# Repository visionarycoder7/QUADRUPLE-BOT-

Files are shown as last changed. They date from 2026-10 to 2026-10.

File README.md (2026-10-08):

# 🐾 8-DOF Quadruped Robot

An **8-DOF quadruped robot** developed as part of the **WTL & MeitY Certification-Based Industrial Training Programme** by **Group-E, Department of Electronics & Communication Engineering, Cooch Behar Government Engineering College (CGEC)**.

The project combines **embedded systems, servo control, mechanical CAD design, 3D printing, and robotics** to develop a four-legged robotic platform capable of stable standing and serving as a foundation for walking gait and autonomous navigation.

---

## 📌 Project Overview

A quadruped robot is a four-legged mobile robot designed to achieve locomotion using coordinated leg movements.

In this project, each leg contains:

- **1 Hip joint**
- **1 Knee joint**

This provides:

> **4 legs × 2 DOF = 8 Degrees of Freedom**

The robot uses an **ESP32** as the central controller and a **PCA9685 16-channel PWM servo driver** to control eight SG90S metal-gear micro servos.

The mechanical structure was designed using **FreeCAD** and fabricated using **FDM 3D printing**.

---

## 🎯 Objectives

The major objectives of the project are:

- Design and develop a functional **8-DOF quadruped robot**
- Implement servo control using an **ESP32**
- Control multiple servos using a **PCA9685 PWM driver**
- Design the robot chassis using **FreeCAD**
- Fabricate mechanical components using **FDM 3D printing**
- Develop and test the electronics and servo-control system
- Implement a stable standing pose
- Establish a foundation for future walking and turning gaits
- Gain practical experience in:
  - Embedded Systems
  - Robotics
  - Electronics
  - Mechanical Design
  - CAD Modelling
  - Additive Manufacturing

---

## 🧠 System Architecture

```text
                 ┌─────────────────────┐
                 │       ESP32          │
                 │  Central Controller  │
                 └──────────┬──────────┘
                            │
                     I2C Communication
                     SDA → GPIO 21
                     SCL → GPIO 22
                            │
                            ▼
                 ┌─────────────────────┐
                 │      PCA9685        │
                 │  16-Channel PWM     │
                 │    Servo Driver     │
                 └──────────┬──────────┘
                            │
              ┌─────────────┼─────────────┐
              │             │             │
              ▼             ▼             ▼
          Hip Servos    Knee Servos    Other Channels
              │             │
              └─────────────┼─────────────┘
                            ▼
                   8 × SG90S Servos
                            │
                            ▼
                    Quadruped Robot
```

### Power Architecture

The ESP32 communicates with the PCA9685 through I2C, while the servo power rail is supplied separately.

```text
External 5V Supply
       │
       ▼
PCA9685 V+ ───────► Servo Power Rail
       │
       ├── CH0 → Front Left Hip
       ├── CH1 → Front Left Knee
       ├── CH2 → Front Right Hip
       ├── CH3 → Front Right Knee
       ├── CH4 → Rear Left Hip
       ├── CH5 → Rear Left Knee
       ├── CH6 → Rear Right Hip
       └── CH7 → Rear Right Knee
```

> ⚠️ **Important:** The PCA9685 `V+` terminal requires an external 5V supply for powering the servos. The PCA9685 `VCC` connection to the ESP32 is for logic power and is not the servo power rail.

---

## 🔌 Electronics Components

| Component | Quantity | Purpose |
|---|---:|---|
| ESP32 Development Board | 1 | Main controller |
| PCA9685 16-Channel PWM Driver | 1 | Multi-servo control |
| SG90S Metal Gear Servo | 8 | Hip & knee actuation |
| 5V External Supply | 1 | Servo power |
| 3D Printed Chassis | 1 set | Mechanical structure |
| Power Switch | 1 | Power control |

---

## 📡 ESP32 → PCA9685 Connections

| ESP32 | PCA9685 |
|---|---|
| 3.3V | VCC |
| GND | GND |
| GPIO 21 | SDA |
| GPIO 22 | SCL |

### PCA9685 I2C Address

The PCA9685 was verified using an I2C scanner.

```text
I2C Device Found:
0x40
```

Therefore:

```text
PCA9685 I2C Address = 0x40
```

---

## 🦿 Servo Channel Mapping

The eight servos are connected to PCA9685 channels **CH0–CH7**.

| Channel | Location | Joint |
|---|---|---|
| CH0 | Front Left | Hip |
| CH1 | Front Left | Knee |
| CH2 | Front Right | Hip |
| CH3 | Front Right | Knee |
| CH4 | Rear Left | Hip |
| CH5 | Rear Left | Knee |
| CH6 | Rear Right | Hip |
| CH7 | Rear Right | Knee |

---

# 🛠️ Mechanical Design

The complete chassis was designed using **FreeCAD** using a parametric modelling workflow.

The robot consists primarily of:

1. Core Body
2. Head Box
3. Four Upper Legs
4. Four Lower Legs

### Mechanical Structure

```text
                   HEAD BOX
              ┌───────────────┐
              │ ESP32 +       │
              │ PCA9685       │
              └───────┬───────┘
                      │
              ┌───────┴───────┐
              │   CORE BODY   │
              └─┬───────────┬─┘
                │           │
          Upper Leg     Upper Leg
                │           │
          Lower Leg     Lower Leg
                │           │
              Foot        Foot

          Rear legs follow the
          same 2-DOF structure.
```

---

## 📐 Component Dimensions

| Component | Dimensions |
|---|---|
| Core Body | 110 × 85 × 4 mm |
| Head Box | 85 × 65 × 45 mm |
| Upper Leg | 45 × 10 × 5 mm |
| Lower Leg | 55 × 10 × 5 mm |

### Core Body

The central chassis contains mounting positions for the four hip servos.

### Head Box

The head box houses:

- ESP32
- PCA9685
- Power switch
- Provision for future sensors

### Upper Leg

Each upper leg is driven by a hip servo.

### Lower Leg

Each lower leg is driven by a knee servo.

---

# 🖨️ 3D Printing

The mechanical components were fabricated using **Fused Deposition Modelling (FDM)**.

### Manufacturing Workflow

```text
FreeCAD CAD Model
       ↓
     STL Export
       ↓
      Slicer
       ↓
    G-code
       ↓
   FDM Printer
       ↓
3D Printed Component
       ↓
    Assembly
```

The components were fabricated in the **CGEC 3D Printing Lab**.

---

## 🧱 Materials

Two thermoplastic materials were used:

### ABS

Used for:

- Core Body
- Head Box

Selected for its stiffness and suitability for structural components.

### PLA

Used for:

- 4 × Upper Legs
- 4 × Lower Legs

---

## ⚙️ Printing Parameters

| Parameter | Value |
|---|---:|
| Layer Height | 0.2 mm |
| Infill Density | 40% |
| Perimeter Walls | 4 |
| Nozzle Diameter | 0.4 mm |
| Print Speed | 50 mm/s |
| Support | As required |

---

# 💻 Software & Programming

The project uses the **Arduino IDE** with ESP32 board support.

### Libraries

```cpp
#include <ESP32Servo.h>
#include <Wire.h>
#include <Adafruit_PWMServoDriver.h>
```

### Libraries Used

| Library | Purpose |
|---|---|
| ESP32Servo | Direct servo control using ESP32 PWM |
| Wire | I2C communication |
| Adafruit_PWMServoDriver | PCA9685 servo control |

---

# 🧪 Testing & Debugging

One of the major practical debugging challenges was related to the **PCA9685 servo power rail**.

### Problem

Initially, all eight servos were unresponsive.

The first assumption could have been a problem with:

- ESP32
- I2C communication
- PCA9685
- Software
- Servo connections

However, an I2C scan confirmed:

```text
PCA9685 detected at:
0x40
```

This confirmed that the ESP32 and PCA9685 were communicating correctly.

### Root Cause

The PCA9685 `V+` servo power rail was measured at:

```text
0.10 V
```

instead of the expected approximately:

```text
4.8 – 5.2 V
```

### Solution

An external 5V supply was connected directly to the PCA9685 `V+` terminal.

After the correction:

```text
V+ = 4.92 – 5.05 V
```

The servos immediately responded.

### Key Lesson

> **Always verify the actuator power rail before assuming that the problem is caused by firmware or communication.**

---

# ✅ Testing Results

The complete servo system was tested after resolving the power issue.

### I2C Test

```text
ESP32
  ↓
GPIO21 / GPIO22
  ↓
SDA / SCL
  ↓
PCA9685
  ↓
0x40
```

### Servo Test

All eight servos successfully passed the individual movement test.

| Servo | Channel | 0° | 180° |
|---|---|:---:|:---:|
| Front Left Hip | CH0 | ✅ | ✅ |
| Front Left Knee | CH1 | ✅ | ✅ |
| Front Right Hip | CH2 | ✅ | ✅ |
| Front Right Knee | CH3 | ✅ | ✅ |
| Rear Left Hip | CH4 | ✅ | ✅ |
| Rear Left Knee | CH5 | ✅ | ✅ |
| Rear Right Hip | CH6 | ✅ | ✅ |
| Rear Right Knee | CH7 | ✅ | ✅ |

### Result

**All 8 servos successfully operated across the tested 0°–180° range.**

---

# 🚧 Development Status

The project was divided into nine development phases.

| Phase | Development Stage | Status |
|---:|---|---|
| 1 | Component Verification | ✅ Complete |
| 2 | CAD Design in FreeCAD | ✅ Complete |
| 3 | 3D Printing | ✅ Complete |
| 4 | Servo Calibration | ✅ Complete |
| 5 | Standing Pose | ✅ Complete |
| 6 | Walking Gait | 🔄 In Progress |
| 7 | Turning Gait | 📋 Planned |
| 8 | Sensor Integration | 📋 Planned |
| 9 | Autonomous Navigation | 🔮 Future |

### Current Progress

```text
Completed:  ██████████░░░░░░░░  5 / 9 phases
```

The presentation reports approximately **55% phase completion**.

---

# 🧭 Future Development

The project is intended to evolve beyond the current standing-pose platform.

### Phase 6 — Walking Gait

Develop coordinated leg trajectories and walking patterns using the eight available degrees of freedom.

Potential future implementation:

```text
Inverse Kinematics
       ↓
Leg Trajectory Generation
       ↓
Joint Angle Calculation
       ↓
Servo Commands
       ↓
Walking Gait
```

### Phase 7 — Turning

Implement coordinated movements that allow the robot to turn left and right.

### Phase 8 — Sensor Integration

Future sensors can be integrated to provide environmental awareness.

Possible applications include:

- Obstacle detection
- Distance measurement
- Orientation sensing
- Environmental monitoring

### Phase 9 — Autonomous Navigation

The ESP32's wireless capability provides a foundation for future:

- Wireless teleoperation
- Remote control
- Autonomous navigation
- OTA firmware updates

---

# 🌐 Potential Applications

Quadruped robots can be adapted for several real-world applications:

- 🔍 Search and rescue
- ⚙️ Rough-terrain inspection
- 🎖️ Defence and reconnaissance
- 🏥 Medical and rehabilitation assistance
- 🔬 Robotics research
- 🏭 Industrial inspection
- 🏗️ Infrastructure monitoring

---

# 📁 Suggested Repository Structure

```text
Quadruped-Robot/
│
├── README.md
│
├── Arduino/
│   ├── Servo_Test/
│   │   └── Servo_Test.ino
│   │
│   ├── I2C_Scanner/
│   │   └── I2C_Scanner.ino
│   │
│   └── PCA9685_Control/
│       └── PCA9685_Control.ino
│
├── CAD/
│   ├── Core_Body/
│   ├── Head_Box/
│   ├── Upper_Leg/
│   ├── Lower_Leg/
│   └── Assembly/
│
├── 3D_Models/
│   ├── STL/
│   └── GCODE/
│
├── Documentation/
│   └── Quadruped_Robot_Presentation.pptx
│
└── Images/
    ├── CAD/
    ├── 3D_Printing/
    ├── Electronics/
    └── Final_Robot/
```

---

**WTL & MeitY Certification-Based Industrial Training Programme**

**Department of Electronics & Communication Engineering**  
**Cooch Behar Government Engineering College**  
**2026**

---

# 📚 References

1. Previous Batch Project Report — *3D Printing and Embedded Systems*, CGEC, WTL & MeitY Project, 2024.
2. Espressif Systems — *ESP32 Technical Reference Manual*, v5.3.
3. NXP Semiconductors — *PCA9685 16-channel 12-bit PWM I2C-bus LED Controller Datasheet*.
4. Tower Pro — *SG90S Metal Gear Micro Servo Datasheet*.
5. FreeCAD Community — *FreeCAD: Your Own 3D Parametric Modeler*.

---

# ⭐ Key Takeaways

This project provided hands-on experience in the complete development cycle of a robotic system:

```text
Concept
   ↓
Electronics Design
   ↓
Component Testing
   ↓
CAD Modelling
   ↓
3D Printing
   ↓
Mechanical Assembly
   ↓
Embedded Programming
   ↓
Servo Calibration
   ↓
Standing Pose
   ↓
Walking Gait
   ↓
Autonomous Navigation
```

The completed platform establishes a **functional 8-DOF quadruped hardware and software foundation**, with future work focused on walking gait generation, turning, sensor integration, and autonomous navigation.

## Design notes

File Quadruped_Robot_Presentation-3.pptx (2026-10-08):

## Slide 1

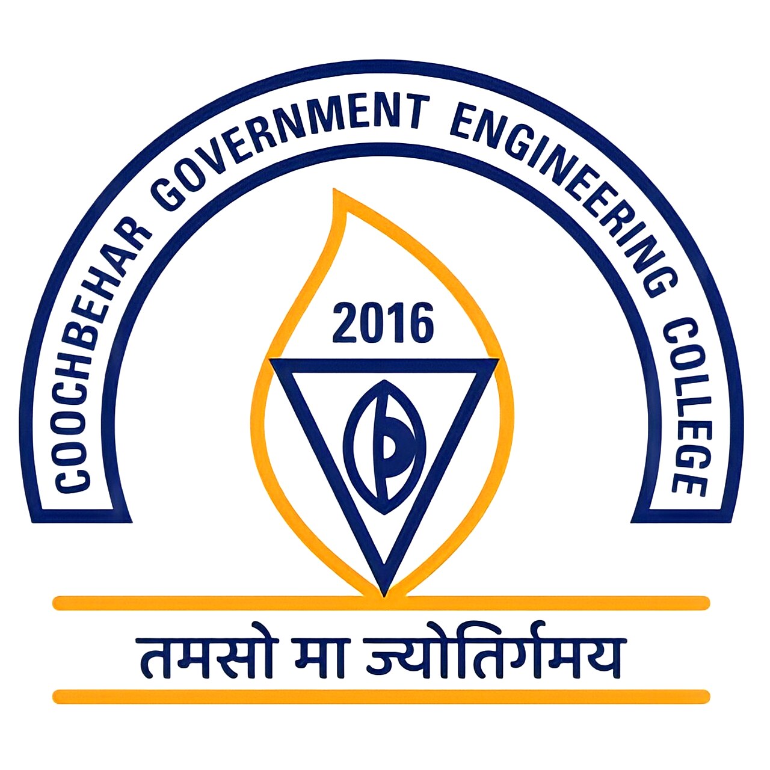
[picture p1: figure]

QUADRUPED ROBOT DEVELOPMENT

━━━━━━━━━━━━━━━━━━━━━━━━━━━━━━━━━━━━━━━━━━━━━

Certification-Based Industrial Training

WTL & MeitY Project | Group-E

Department of Electronics & Communication Engineering

Cooch Behar Government Engineering College | 2026

Guided by: Dr. Palash Das (ECE) | Mrs. Susmita Banik Barik (Project Eng., WTL) | Mr. Arijit Bhunia | Mr. Bhaskar Mondal

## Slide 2

Team Members — Group E

Department of ECE, CGEC | WTL & MeitY Project | 2026

Quadruped Robot Development | Group-E | ECE Dept., CGEC | WTL & MeitY | 2026

Name

Roll No.

Reg. ID

GUIDED BY

Dr. Palash Das

ECE

Mrs. Susmita

Banik Barik

Proj. Eng., WTL

Mr. Arijit Bhunia

Proj. Co-ord.

Mr. Bhaskar

Mondal

Faculty, WTL

2/21

1

2

Sarupya Guha

Sohan Ghosh

34900323046

34900323050

FS08A0198

FS08A0202

3

Sayan Sarkar

34900323048

FS08A0157

4

Debanjan Chakraborty

34900323015

FS08A0154

5

6

Joydip Das

Aushi Sarkar

34900323020

34900323011

FS08A0220

FS08A0288

7

Anupam Dutta

34900323003

FS08A0206

8

9

Bikkram Das

Biraj Sarkar

34900323012

34900323013

FS08A0528

FS08A0239

10

Soumyajit Pandit

34900323052

FS08A0189

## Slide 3

Project Objective

What are we building and why?

Design, fabricate & program a fully functional 8-DOF Quadruped Robot

Use affordable, open-source components and tools (ESP32 + FreeCAD + FDM printing)

Core hardware: ESP32 microcontroller | PCA9685 16-ch servo driver | 8 × SG90S servos

Chassis designed in FreeCAD — fabricated with FDM 3D printing (PLA+ & ABS)

Hands-on experience across: Electronics • Mechanical Design • Additive Manufacturing

End goal: Robot capable of standing stably and executing a walking gait

Future roadmap: Sensor integration → Autonomous navigation

Aligned with GoI skills development initiative under WTL & MeitY programme

Quadruped Robot Development | Group-E | ECE Dept., CGEC | WTL & MeitY | 2026

▶

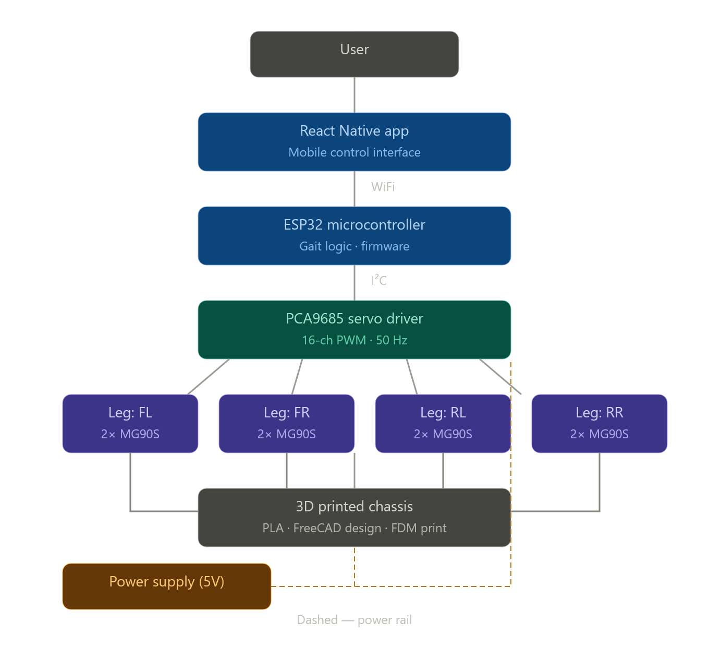
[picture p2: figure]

▶

▶

▶

▶

▶

▶

▶

3/21

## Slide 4

Introduction — What is a Quadruped Robot?

A legged mobile robot that moves on four limbs — mimicking dogs, horses, insects

Unlike wheeled robots, quadrupeds navigate uneven terrain, climb stairs, step over obstacles

Each leg has 2+ joints providing degrees of freedom for stable gait generation

This robot: Hip joint + Knee joint per leg → 8 DOF for locomotion

Notable examples: Boston Dynamics Spot • Unitree Go1 • University research platforms

Quadruped Robot Development | Group-E | ECE Dept., CGEC | WTL & MeitY | 2026

▶

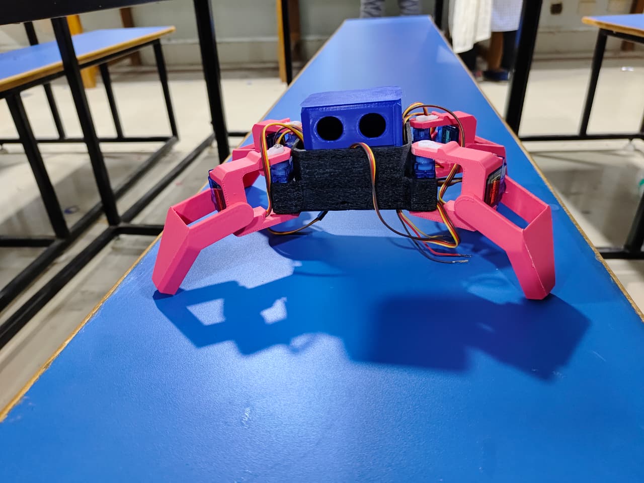
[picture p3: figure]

▶

▶

▶

▶

8 DOF

Locomotion
(4 hips + 4 knees)

Static Head

Head
is stationary

8 Total

SG90S
Servos

3 Domains

Electronics
Mechanical
3D Printing

4/21

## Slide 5

Real-World Applications of Quadruped Robots

Quadruped Robot Development | Group-E | ECE Dept., CGEC | WTL & MeitY | 2026

🔍 Search & Rescue

Navigates rubble, collapsed structures and disaster zones where wheels cannot go

🏥 Medical / Rehab

Companion and assistive robots for elderly care and rehabilitation

⚙ Rough Terrain

Pipeline inspection, mining surveys, and remote area monitoring

🔬 Research Platform

Studying locomotion algorithms, control theory, and AI-based navigation

🎖 Military / Defence

Cargo carrying, reconnaissance missions, and hazardous environment scouting

🏭 Industrial

Automated factory floor inspection and infrastructure monitoring

5/21

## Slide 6

Why ESP32? & Why 3D Printing?

Quadruped Robot Development | Group-E | ECE Dept., CGEC | WTL & MeitY | 2026

ESP32 — Central Controller

3D Printing — Chassis Fabrication

▶

Dual-core 240 MHz processor — powerful yet low-cost

▶

Rapid iteration on part dimensions without tooling cost

▶

▶

Built-in Wi-Fi & Bluetooth for wireless control

Supports I2C and SPI for peripheral communication

▶

▶

Customised mounting positions for every component

Fabricate geometrically complex parts cheaply

PLA+ → structural rigidity for Core Body & Head Box

ABS → flexibility & impact resistance for leg links

▶

Well-supported Arduino IDE ecosystem

▶

▶

ESP32Servo library — direct servo control via PWM

▶

▶

Wireless capability → OTA updates, remote teleoperation

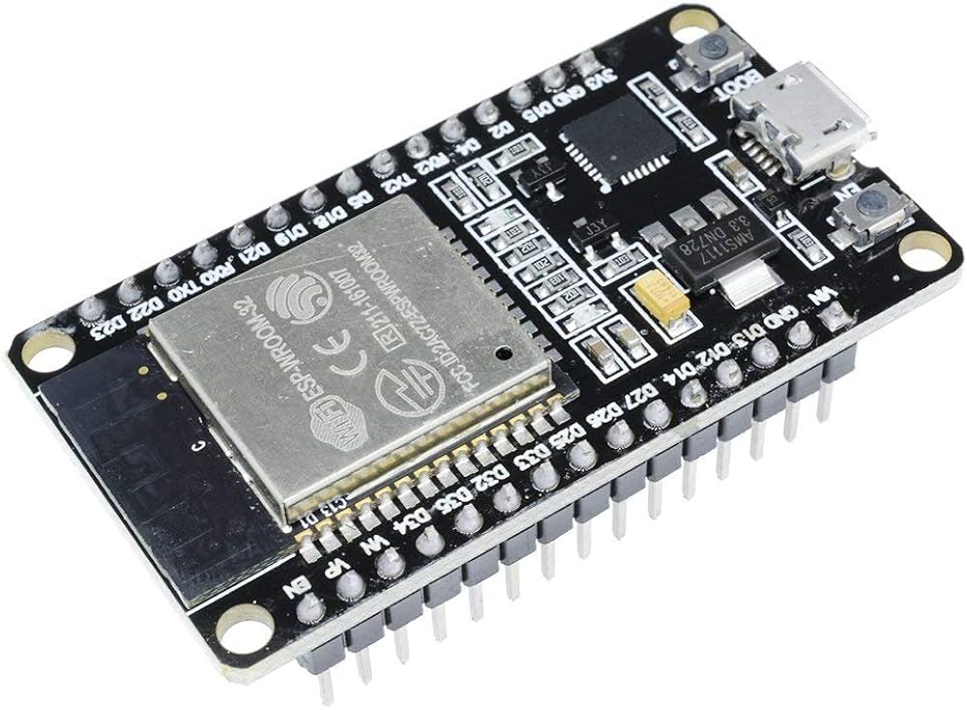
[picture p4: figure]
SquadPixel Esp-32 Wifi, Bluetooth, Dual Core Chip Development Board (ESP-WROOM-32) : Amazon.in: Fashion

▶

Entire robot chassis printed in the CGEC 3D Printing Lab

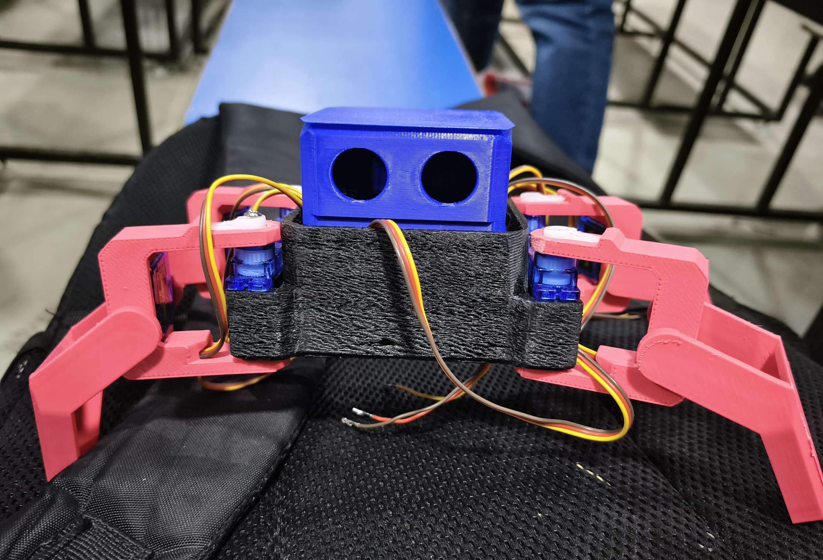
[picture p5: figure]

6/21

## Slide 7

Development Roadmap — 9-Phase Journey

From component verification to autonomous navigation

📌 This report covers Phases 1–5 in detail. Phases 6–9 form the future roadmap.

Quadruped Robot Development | Group-E | ECE Dept., CGEC | WTL & MeitY | 2026

Phase 1

Servo &
MCU Test

Complete

Phase 2

CAD
Design

Complete

Complete

Phase 3

3D
Printing

Complete

Phase 4

Assembly

Complete

In Progress / Planned

Phase 5

Standing
Pose

Complete

Phase 6

Walking
Gait

In Progress

Future Roadmap

Phase 7

Turning
Gait

Planned

Phase 8

Sensor
Integration

Future

Phase 9

Autonomous
Nav.

Future

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
7/21

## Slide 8

Electronics Architecture

4-Layer electronics stack

Layer 1 — Central Controller

ESP32 Dev Board (I2C Master, Dual-core 240 MHz)

Layer 2 — Servo Driver

PCA9685 16-Channel PWM Driver (I2C Slave @ 0x40)

Layer 3 — Actuators

8× SG90S Metal Gear Micro Servos (4 Hip + 4 Knee)

Layer 4 — Power Supply

External 5V Supply → PCA9685 V+ Servo Rail

Quadruped Robot Development | Group-E | ECE Dept., CGEC | WTL & MeitY | 2026

ESP32 → PCA9685 Wiring

ESP32 Pin

3.3V

PCA9685 Pin

VCC

▼

GND

GND

▼

GPIO21

GPIO22

SDA

SCL

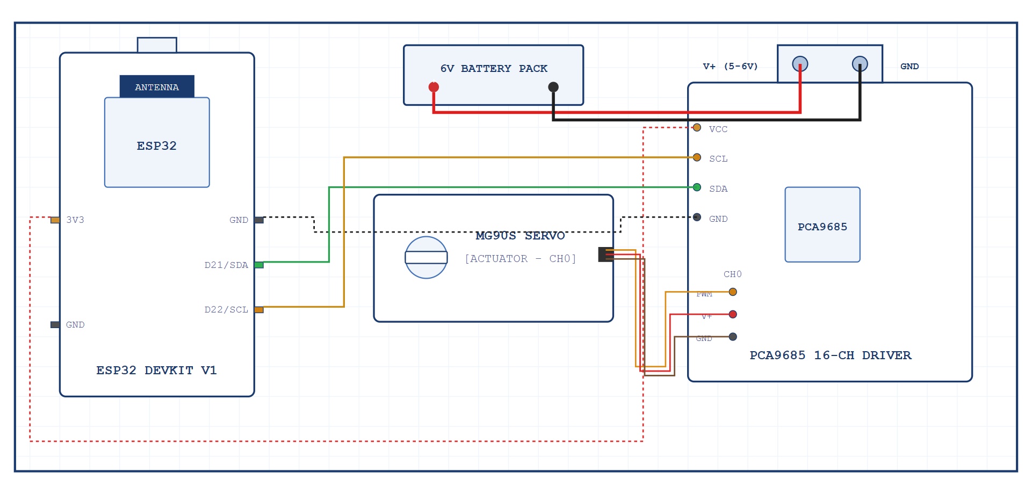
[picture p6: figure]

⚠ PCA9685 V+ rail MUST have
an external 5V supply (separate from VCC)

▼

8/21

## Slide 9

Servo Channel Mapping

PCA9685 CH0–CH7 → 8 SG90S servos

Quadruped Robot Development | Group-E | ECE Dept., CGEC | WTL & MeitY | 2026

CH0

Front Left Hip

Type: Hip

CH5

Rear Left Knee

Type: Knee

CH1

Front Left Knee

Type: Knee

CH6

Rear Right Hip

Type: Hip

CH2

Front Right Hip

Type: Hip

CH7

Rear Right Knee

Type: Knee

CH3

Front Right Knee

Type: Knee

CH4

Rear Left Hip

Type: Hip

Hip Servo

Knee Servo

Head Servo

9/21

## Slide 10

Critical Discovery — Servo Power Rail Issue

Real-world debugging experience during Phase 1

All 8 servos were completely unresponsive when controlled via PCA9685

I2C scanner confirmed PCA9685 at address 0x40 — ESP32, I2C bus, and chip all functioning correctly

V+ rail measured only 0.10 V (expected 4.8–5.2 V) — servo power rail NOT connected to external 5V supply

Connected 5V directly to PCA9685 V+ terminal → Servos responded immediately. V+ measured 4.92–5.05 V

Always verify servo rail voltage FIRST before suspecting firmware or I2C communication issues

Quadruped Robot Development | Group-E | ECE Dept., CGEC | WTL & MeitY | 2026

⚠ SYMPTOM

🔍 I2C DIAGNOSIS

🔎 ROOT CAUSE

✅ RESOLUTION

📖 LESSON

10/21

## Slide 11

Mechanical Architecture & Component Dimensions

FreeCAD-designed chassis — all parts 3D printed

Quadruped Robot Development | Group-E | ECE Dept., CGEC | WTL & MeitY | 2026

Structural Overview

Component Dimensions

▶

Two main assemblies: Head Box (electronics enclosure) + Core Body (central chassis)

Head Box — houses ESP32, PCA9685, power switch + future sensor mount provision

Core Body — mounts all 4 hip servos (4 total on chassis)

Component

Core Body

Dimensions (mm)

110 × 85 × 4

Notes

4 hip mounts

▶

▶

Head Box

85 × 65 × 45

Wall 2.5 mm — ESP32, PCA9685

▶

Each leg: Upper Leg (hip-driven) + Lower Leg (knee-driven) → 2 links per leg

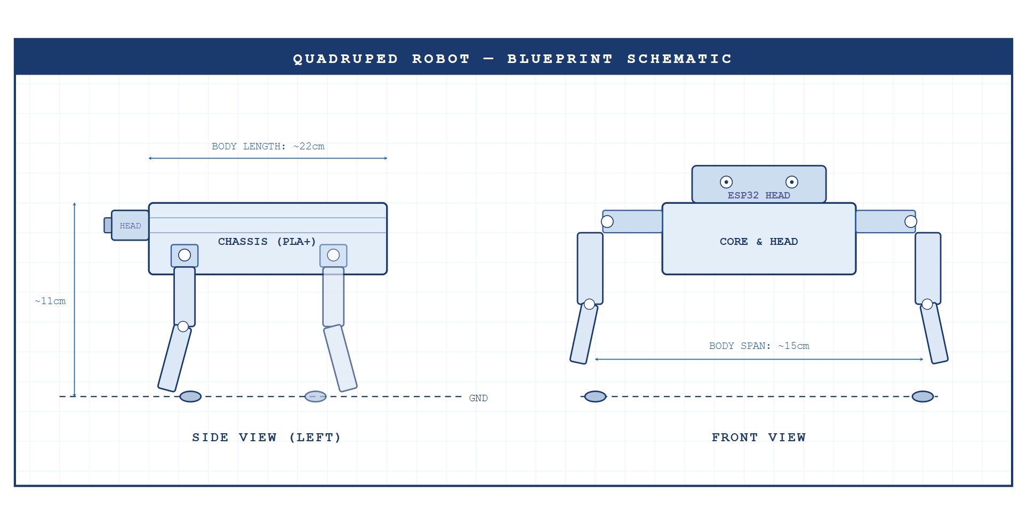
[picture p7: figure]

Upper Leg ×4

45 × 10 × 5

PLA+ — hip servo driven

Lower Leg ×4

55 × 10 × 5

PLA+ — knee servo driven

11/21

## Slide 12

FreeCAD Design Workflow

Part Design workbench — parametric modelling

Quadruped Robot Development | Group-E | ECE Dept., CGEC | WTL & MeitY | 2026

1

Core Body

Base 110×85×4 mm plate with 4 symmetric hip servo pockets and central head servo mount

4

Upper Leg

45 mm PLA link with servo horn connection hole at proximal end

2

Head Box

Enclosure designed around ESP32 and PCA9685 PCB footprints (85×65×45 mm)

5

Hip

Lower Leg

Four symmetric press-fit pockets at FL, FR, RL, RR corners

55 mm PLA link with foot pad boss at distal (terminal) end

3

4

Hip Servo Mounts

Four symmetric press-fit pockets at FL, FR, RL, RR corners

6

Assembly

All bodies assembled in FreeCAD Assembly with correct spacing and constraints

12/21

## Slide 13

3D Printing Process — FDM Technology

CAD → STL → G-code → Print

Fused Deposition Modelling (FDM): thermoplastic filament melted & deposited layer-by-layer | Workflow: CAD Model → STL Export → Slicer (G-code) → 3D Printer

Quadruped Robot Development | Group-E | ECE Dept., CGEC | WTL & MeitY | 2026

Material Selection

Slicer Settings

ABS

Core Body, Head Box

High stiffness, low warping, easy to print

Parameter

Value

Layer Height

Infill Density

0.2 mm

40%

PLA

Upper Leg, Lower Leg (×4 each)

Toughness & flexibility for repeated bending/impact loads

Perimeter Walls

4

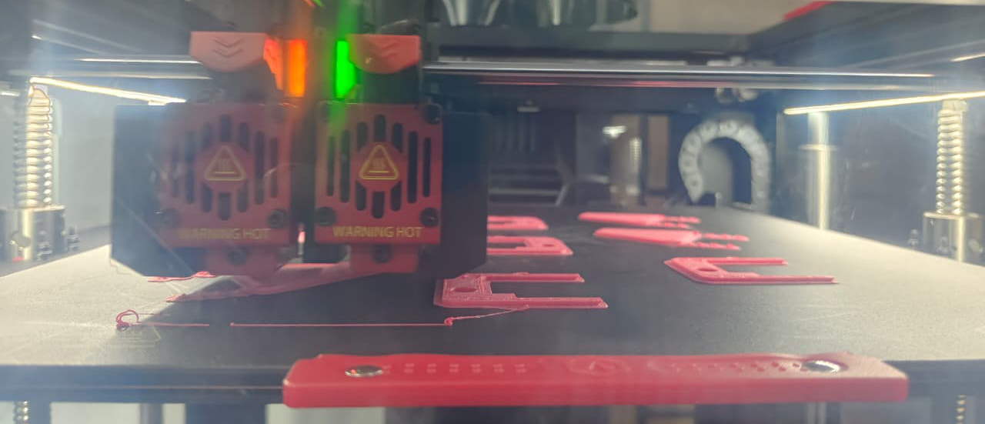
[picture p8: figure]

Nozzle Diameter

Print Speed

0.4 mm

50 mm/s

Support

As required

13/21

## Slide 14

3D Printing in the Lab

Fabrication of quadruped robot components at CGEC 3D Printing Lab

Quadruped Robot Development | Group-E | ECE Dept., CGEC | WTL & MeitY | 2026

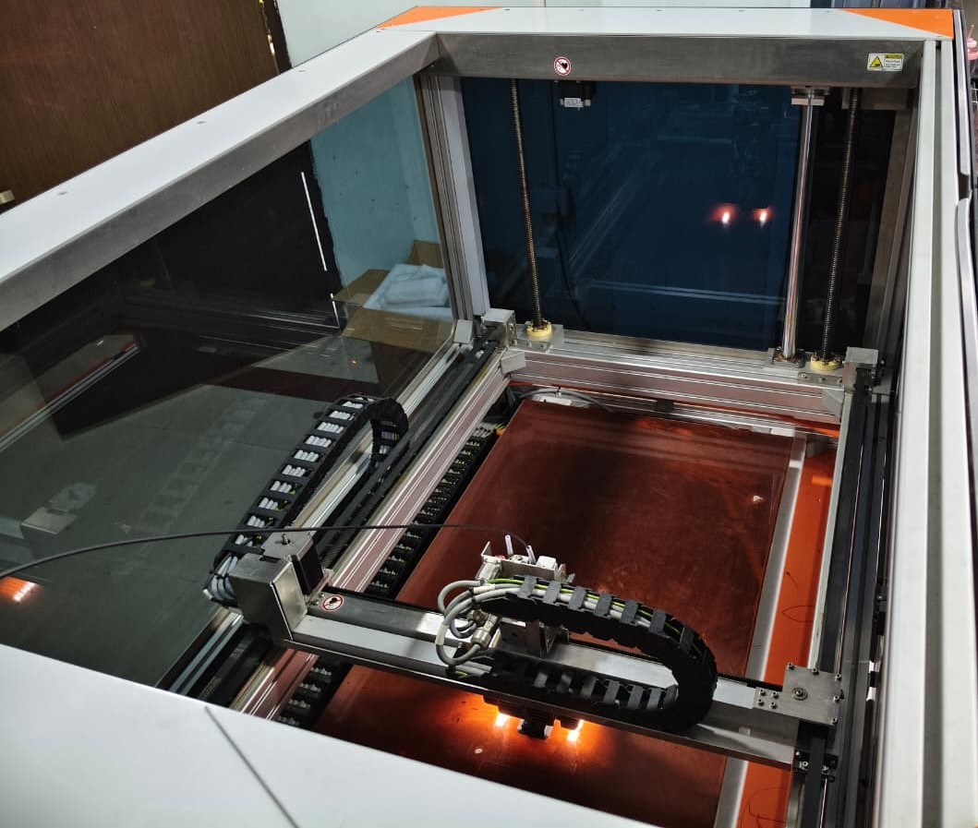
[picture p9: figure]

3D Printer (FDM) in the CGEC Lab during fabrication of the Core Body and Head Box using ABS.

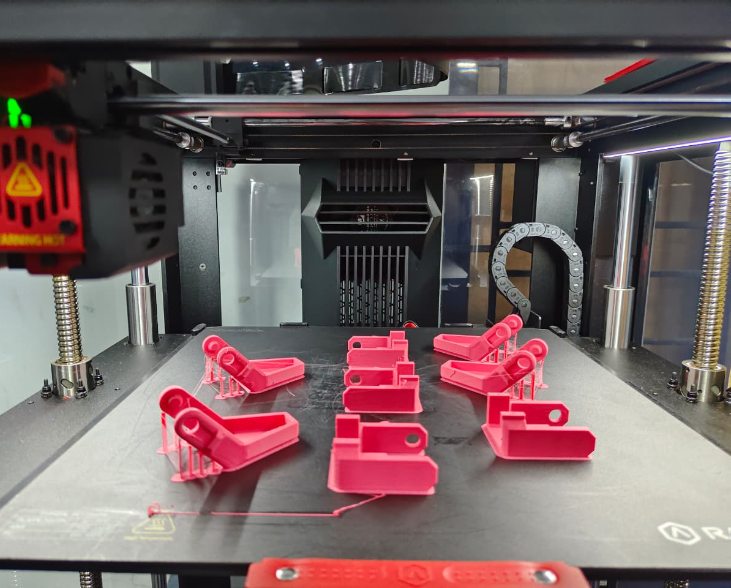
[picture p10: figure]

Fabricated leg components (Upper and Lower leg segments) printed in magenta PLA for high layer adhesion and impact strength.

14/21

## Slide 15

Products Made — 3D Printed Parts

19 total printed components

Description

Quadruped Robot Development | Group-E | ECE Dept., CGEC | WTL & MeitY | 2026

Part

Material

Dimensions

Qty

Core Body

ABS

110×85×4 mm

1

Central chassis; 4 hip mounts; 4mm thickness for bending rigidity

Head Box

ABS

85×65×45 mm

1

Electronics enclosure for ESP32, PCA9685 & power switch; 2.5mm walls; future sensor provision

Upper Leg

PLA

45×10×5 mm

4

Hip-servo driven link; servo horn attachment hole at proximal end

Lower Leg

PLA

55×10×5 mm

4

Knee-servo driven link; foot pad boss at distal terminal end

15/21

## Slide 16

Arduino Programming

Arduino IDE + ESP32 board support package

Quadruped Robot Development | Group-E | ECE Dept., CGEC | WTL & MeitY | 2026

Development Environment & Libraries

// Servo Test Code — ESP32 direct GPIO18

#include <ESP32Servo.h>

Servo myServo;

void setup() {

myServo.attach(18); // GPIO18

}

void loop() {

myServo.write(0); delay(1000);

myServo.write(90); delay(1000);

myServo.write(180); delay(1000);

}

ESP32Servo

Direct servo control via GPIO PWM

Wire

I2C communication for PCA9685

Adafruit_PWMServoDriver

High-level PCA9685 servo control

Code Listings

Listing 1

Servo Test Code: Direct GPIO18 sweep — 0° → 90° → 180° per servo

Listing 2

PCA9685 I2C Scanner: Scans I2C bus, confirms address 0x40

Listing 3

I2C Scan Output: Expected serial monitor: 'I2C device found at 0x40'

Listing 4

PCA9685 Servo Control: All-channel sweep through Adafruit PWM library

16/21

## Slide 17

Results & Testing

I2C verification · Power rail · All-servo sweep

Quadruped Robot Development | Group-E | ECE Dept., CGEC | WTL & MeitY | 2026

I2C Communication Verification

Individual Servo Test Results (All 8 Passed)

PCA9685 confirmed at address 0x40 via I2C scanner

Full chain validated: ESP32 → GPIO21/22 → SDA/SCL → PCA9685

1

Function

Front Left Hip (CH0)

0°

✓ Pass

180°

✓ Pass

Power Rail Diagnosis & Resolution

2

Front Left Knee (CH1)

✓ Pass

✓ Pass

Before fix: V+ = 0.10 V (expected 4.8–5.2 V)

3

Front Right Hip (CH2)

✓ Pass

✓ Pass

After fix: V+ = 4.92–5.05 V → All servos responded immediately

4

5

Front Right Knee (CH3)

Rear Left Hip (CH4)

✓ Pass

✓ Pass

✓ Pass

✓ Pass

6

Rear Left Knee (CH5)

✓ Pass

✓ Pass

7

Rear Right Hip (CH6)

✓ Pass

✓ Pass

8

Rear Right Knee (CH7)

✓ Pass

✓ Pass

17/21

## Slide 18

Development Phase Status

Current progress across all 9 phases

Quadruped Robot Development | Group-E | ECE Dept., CGEC | WTL & MeitY | 2026

1

Component Verification

Complete

6

Walking Gait

In Progress

2

CAD Design in FreeCAD

Complete

7

Turning Gait

Planned

3

3D Printing All Parts

Complete

8

Sensor Integration

Planned

4

Servo Calibration

Complete

9

Autonomous Navigation

Future

5

Standing Pose

Complete

55% Complete (5 of 9 Phases)

18/21

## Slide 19

Conclusion

Key achievements and future roadmap

Systematic debugging validated: I2C chain, servo power rail fix, all 8 servos operational across full 0°–180° range

Parametric FreeCAD CAD workflow mastered: , press-fit tolerances, STL export → design-for-manufacture skills

Hands-on material selection (PLA & ABS), slicer optimization, and print quality assessment in CGEC Lab

Fully functional 8-DOF quadruped hardware + software stack built — validated foundation for walking gait development

Roadmap: Phase 6 Walking Gait (IK) → Phase 7 Turning → Phase 8 Sensors → Phase 9 Autonomous Navigation via ESP32 Wi-Fi

Quadruped Robot Development | Group-E | ECE Dept., CGEC | WTL & MeitY | 2026

Electronics

Mechanical Design

3D Printing

Overall Platform

19/21

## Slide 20

References

Previous Batch Project Report — 3D Printing and Embedded Systems, CGEC Dept. of ECE, WTL & MeitY Project, Cooch Behar, West Bengal, 2024

Espressif Systems, ESP32 Technical Reference Manual, v5.3, Espressif Systems, 2024

NXP Semiconductors, PCA9685 16-channel 12-bit PWM I2C-bus LED controller, Product datasheet Rev. 4, NXP, 2015

Tower Pro, SG90S Metal Gear Micro Servo Datasheet, Tower Pro Co. Ltd., 2020

FreeCAD Community, FreeCAD: Your Own 3D Parametric Modeler, https://www.freecad.org

Quadruped Robot Development | Group-E | ECE Dept., CGEC | WTL & MeitY | 2026

[1]

[2]

[3]

[4]

[5]

20/21

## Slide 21

THANK YOU

━━━━━━━━━━━━━━━━━━━━━━━━━━━━━━━━━━━━━━━━━━━━━

Quadruped Robot Development | Group-E | CGEC 2026

WTL & MeitY Industrial Training Programme

Guided by: Dr. Palash Das · Mrs. Susmita Banik Barik · Mr. Arijit Bhunia · Mr. Bhaskar Mondal

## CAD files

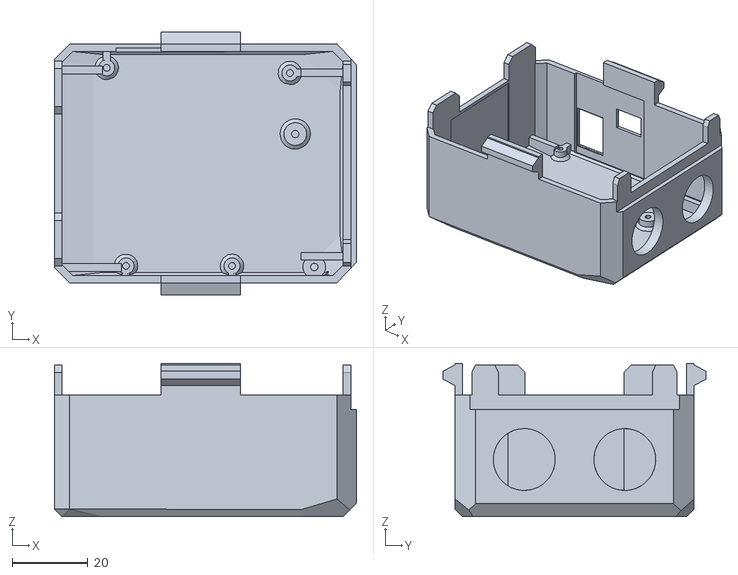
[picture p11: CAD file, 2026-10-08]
Files for 3d printing/OttoQuadBigger_head.stl
79.5 x 69.2 x 40.4

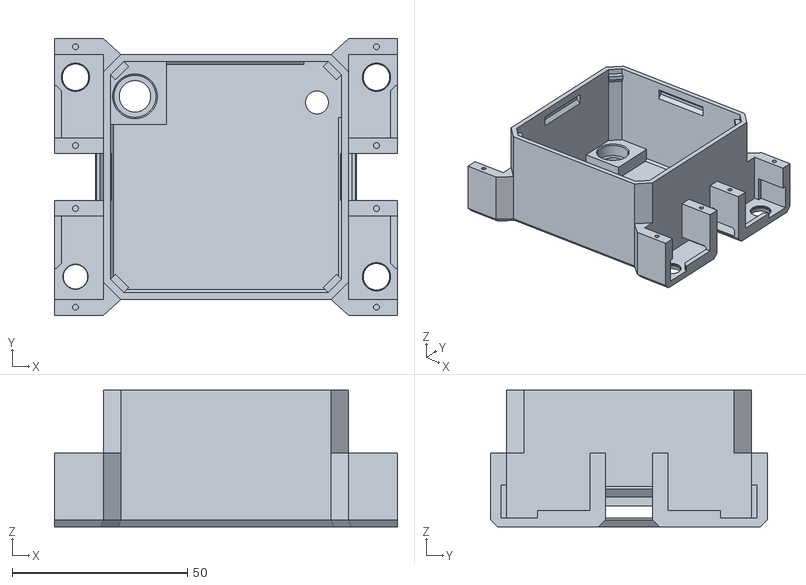
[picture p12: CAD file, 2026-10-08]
Files for 3d printing/OttoQuadBodyV13.stl
98.0 x 79.0 x 39.0

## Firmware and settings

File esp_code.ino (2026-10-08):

/*
 * ============================================================
 *          8-DOF QUADRUPED ROBOT
 * ============================================================
 *
 * Controller : ESP32
 * Servo Driver: PCA9685 16-Channel PWM
 * Servos      : 8 x SG90S
 *
 * I2C:
 * SDA -> GPIO 21
 * SCL -> GPIO 22
 *
 * PCA9685 Address:
 * 0x40
 *
 * Servo Mapping:
 *
 * CH0 -> Front Left Hip
 * CH1 -> Front Left Knee
 *
 * CH2 -> Front Right Hip
 * CH3 -> Front Right Knee
 *
 * CH4 -> Rear Left Hip
 * CH5 -> Rear Left Knee
 *
 * CH6 -> Rear Right Hip
 * CH7 -> Rear Right Knee
 *
 * ============================================================
 */

#include <Wire.h>
#include <Adafruit_PWMServoDriver.h>

// ------------------------------------------------------------
// PCA9685
// ------------------------------------------------------------

Adafruit_PWMServoDriver pwm = Adafruit_PWMServoDriver(0x40);

// PCA9685 PWM frequency for servos
#define SERVO_FREQ 50

// ------------------------------------------------------------
// Servo Channels
// ------------------------------------------------------------

// Front Left
#define FL_HIP   0
#define FL_KNEE  1

// Front Right
#define FR_HIP   2
#define FR_KNEE  3

// Rear Left
#define RL_HIP   4
#define RL_KNEE  5

// Rear Right
#define RR_HIP   6
#define RR_KNEE  7


// ------------------------------------------------------------
// Servo Calibration
// ------------------------------------------------------------

// Typical SG90 servo pulse range.
// These values may need adjustment for your particular servos.

#define SERVO_MIN  110
#define SERVO_MAX  500


// ------------------------------------------------------------
// Convert angle to PCA9685 pulse
// ------------------------------------------------------------

int angleToPulse(int angle)
{
  angle = constrain(angle, 0, 180);

  return map(angle, 0, 180, SERVO_MIN, SERVO_MAX);
}


// ------------------------------------------------------------
// Move one servo
// ------------------------------------------------------------

void setServo(int channel, int angle)
{
  angle = constrain(angle, 0, 180);

  int pulse = angleToPulse(angle);

  pwm.setPWM(channel, 0, pulse);
}


// ------------------------------------------------------------
// Move servo smoothly
// ------------------------------------------------------------

void smoothServo(int channel, int startAngle, int endAngle, int delayTime)
{
  if (startAngle < endAngle)
  {
    for (int angle = startAngle; angle <= endAngle; angle++)
    {
      setServo(channel, angle);
      delay(delayTime);
    }
  }
  else
  {
    for (int angle = startAngle; angle >= endAngle; angle--)
    {
      setServo(channel, angle);
      delay(delayTime);
    }
  }
}


// ------------------------------------------------------------
// Set all servos
// ------------------------------------------------------------

void setAllServos(int angle)
{
  for (int channel = 0; channel < 8; channel++)
  {
    setServo(channel, angle);
  }
}


// ------------------------------------------------------------
// Servo Test
// ------------------------------------------------------------

void servoTest()
{
  Serial.println("Starting servo test...");

  for (int channel = 0; channel < 8; channel++)
  {
    Serial.print("Testing Servo Channel: ");
    Serial.println(channel);

    setServo(channel, 90);
    delay(500);

    setServo(channel, 0);
    delay(500);

    setServo(channel, 180);
    delay(500);

    setServo(channel, 90);
    delay(500);
  }

  Serial.println("Servo test completed.");
}


// ============================================================
//              QUADRUPED POSITIONS
// ============================================================

/*
 * IMPORTANT:
 *
 * These angles are starting values only.
 *
 * Depending on how your servos are physically mounted,
 * some joints may need their angles reversed.
 *
 * Tune these values after assembling the robot.
 */


// ------------------------------------------------------------
// Standing Position
// ------------------------------------------------------------

void stand()
{
  Serial.println("Robot -> STANDING");

  // Front Left
  setServo(FL_HIP, 90);
  setServo(FL_KNEE, 90);

  // Front Right
  setServo(FR_HIP, 90);
  setServo(FR_KNEE, 90);

  // Rear Left
  setServo(RL_HIP, 90);
  setServo(RL_KNEE, 90);

  // Rear Right
  setServo(RR_HIP, 90);
  setServo(RR_KNEE, 90);

  delay(1000);
}


// ------------------------------------------------------------
// Sit Position
// ------------------------------------------------------------

void sit()
{
  Serial.println("Robot -> SITTING");

  // Front legs
  setServo(FL_HIP, 90);
  setServo(FL_KNEE, 140);

  setServo(FR_HIP, 90);
  setServo(FR_KNEE, 140);

  // Rear legs
  setServo(RL_HIP, 90);
  setServo(RL_KNEE, 40);

  setServo(RR_HIP, 90);
  setServo(RR_KNEE, 40);

  delay(1000);
}


// ------------------------------------------------------------
// Neutral Position
// ------------------------------------------------------------

void neutral()
{
  Serial.println("Robot -> NEUTRAL");

  setServo(FL_HIP, 90);
  setServo(FL_KNEE, 90);

  setServo(FR_HIP, 90);
  setServo(FR_KNEE, 90);

  setServo(RL_HIP, 90);
  setServo(RL_KNEE, 90);

  setServo(RR_HIP, 90);
  setServo(RR_KNEE, 90);
}


// ============================================================
//              BASIC LEG MOVEMENTS
// ============================================================

// ------------------------------------------------------------
// Lift Front Left Leg
// ------------------------------------------------------------

void liftFrontLeft()
{
  Serial.println("Lifting Front Left Leg");

  setServo(FL_HIP, 70);
  setServo(FL_KNEE, 130);

  delay(500);
}


// ------------------------------------------------------------
// Lift Front Right Leg
// ------------------------------------------------------------

void liftFrontRight()
{
  Serial.println("Lifting Front Right Leg");

  setServo(FR_HIP, 110);
  setServo(FR_KNEE, 130);

  delay(500);
}


// ------------------------------------------------------------
// Lift Rear Left Leg
// ------------------------------------------------------------

void liftRearLeft()
{
  Serial.println("Lifting Rear Left Leg");

  setServo(RL_HIP, 70);
  setServo(RL_KNEE, 50);

  delay(500);
}


// ------------------------------------------------------------
// Lift Rear Right Leg
// ------------------------------------------------------------

void liftRearRight()
{
  Serial.println("Lifting Rear Right Leg");

  setServo(RR_HIP, 110);
  setServo(RR_KNEE, 50);

  delay(500);
}


// ============================================================
//              SIMPLE WALKING SEQUENCE
// ============================================================

void walkForward()
{
  Serial.println("Robot -> WALK FORWARD");

  /*
   * Basic diagonal gait:
   *
   * Pair 1:
   * Front Left + Rear Right
   *
   * Pair 2:
   * Front Right + Rear Left
   *
   * This is a starting gait and will require
   * mechanical tuning.
   */

  // ----------------------------------------------------------
  // STEP 1
  // Lift diagonal pair
  // ----------------------------------------------------------

  setServo(FL_HIP, 70);
  setServo(FL_KNEE, 130);

  setServo(RR_HIP, 110);
  setServo(RR_KNEE, 50);

  delay(300);


  // ----------------------------------------------------------
  // Move lifted legs forward
  // ----------------------------------------------------------

  setServo(FL_HIP, 110);
  setServo(RR_HIP, 70);

  delay(300);


  // ----------------------------------------------------------
  // Put legs down
  // ----------------------------------------------------------

  setServo(FL_KNEE, 90);
  setServo(RR_KNEE, 90);

  delay(300);


  // ----------------------------------------------------------
  // STEP 2
  // Other diagonal pair
  // ----------------------------------------------------------

  setServo(FR_HIP, 110);
  setServo(FR_KNEE, 130);

  setServo(RL_HIP, 70);
  setServo(RL_KNEE, 50);

  delay(300);


  // Move legs forward

  setServo(FR_HIP, 70);
  setServo(RL_HIP, 110);

  delay(300);


  // Put legs down

  setServo(FR_KNEE, 90);
  setServo(RL_KNEE, 90);

  delay(300);
}


// ============================================================
//              SERIAL COMMAND SYSTEM
// ============================================================

void serialCommands()
{
  if (Serial.available())
  {
    char command = Serial.read();

    switch (command)
    {
      case 's':
        stand();
        break;

      case 'x':
        sit();
        break;

      case 'n':
        neutral();
        break;

      case 't':
        servoTest();
        break;

      case 'w':
        walkForward();
        break;

      case '1':
        liftFrontLeft();
        break;

      case '2':
        liftFrontRight();
        break;

      case '3':
        liftRearLeft();
        break;

      case '4':
        liftRearRight();
        break;

      default:
        Serial.println("Unknown command.");
        break;
    }
  }
}


// ============================================================
//                     SETUP
// ============================================================

void setup()
{
  Serial.begin(115200);

  delay(1000);

  Serial.println();
  Serial.println("====================================");
  Serial.println("   8-DOF QUADRUPED ROBOT");
  Serial.println("====================================");

  // Initialize I2C
  Wire.begin(21, 22);

  Serial.println("Initializing PCA9685...");

  // Initialize PCA9685
  pwm.begin();

  // Set servo PWM frequency
  pwm.setOscillatorFrequency(27000000);
  pwm.setPWMFreq(SERVO_FREQ);

  delay(500);

  Serial.println("PCA9685 initialized.");
  Serial.println("I2C Address: 0x40");
  Serial.println("Servo Frequency: 50 Hz");

  // Move robot to neutral position
  neutral();

  delay(1000);

  Serial.println();
  Serial.println("Commands:");
  Serial.println("-----------------------------");
  Serial.println("s = Stand");
  Serial.println("x = Sit");
  Serial.println("n = Neutral");
  Serial.println("t = Servo Test");
  Serial.println("w = Walk Forward");
  Serial.println("1 = Lift Front Left");
  Serial.println("2 = Lift Front Right");
  Serial.println("3 = Lift Rear Left");
  Serial.println("4 = Lift Rear Right");
  Serial.println("-----------------------------");
}


// ============================================================
//                      LOOP
// ============================================================

void loop()
{
  serialCommands();
}

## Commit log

2026-10-08 Create STL FILES
2026-10-08 Add ESP32 quadruped robot control code
    This code implements an 8-DOF quadruped robot controller using an ESP32 and PCA9685 for servo control. It includes functions for various movements and a serial command system for user interaction.
